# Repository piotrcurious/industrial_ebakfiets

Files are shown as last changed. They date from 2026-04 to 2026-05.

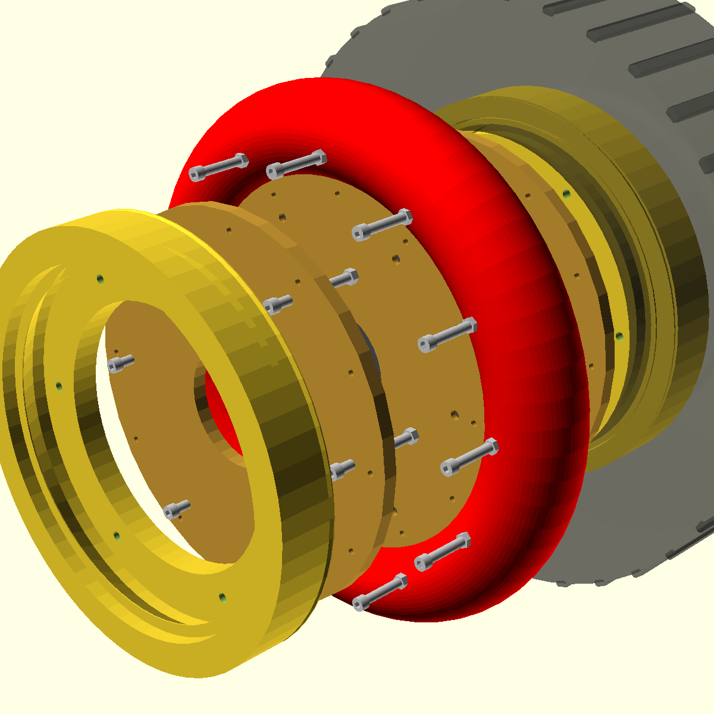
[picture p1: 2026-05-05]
docs/renders/front_wheel_exploded.png

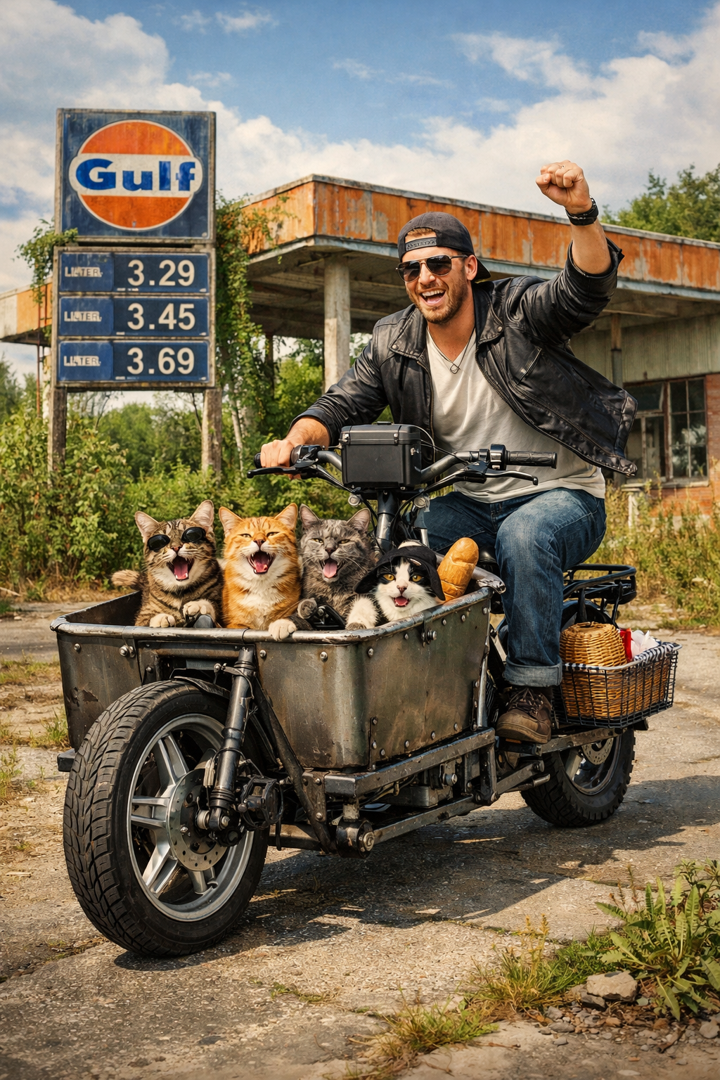
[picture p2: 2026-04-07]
file_000000008bf07243b2001178febfed57.png

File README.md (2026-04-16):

# Industrial E-Bakfiets

Welcome to the **industrial_ebakfiets** repository. This project aims to design and build heavy-duty cargo e-bikes using standard, widely available industrial and automotive parts.

## Project Concept

The **Industrial E-Bakfiets** takes a different approach:
- **Prioritize Durability and Serviceability**: Use heavy-duty parts that are easy to find and replace.
- **Electric-First Design**: Leverage powerful motors to offset the weight of a robust frame.
- **Automotive Components**: Incorporate standard car tires and split rims.

## 3D Mechanical Design (OpenSCAD)

The project features a full 3D mechanical model developed in **OpenSCAD**, ensuring dimensional accuracy and zero mechanical interference.

### Visual Renders (Orthographic & Perspective)
- **[Full Assembly Perspective](docs/renders/full_assembly_perspective.png)**
- **[Frame Side View](docs/renders/frame_side.png)**
- **[Front Fork Front View](docs/renders/front_fork_front.png)**
- **[Steering Head Section](docs/renders/steering_head_perspective.png)**
- **[Wheel & Hub Assembly](docs/renders/front_wheel_assy_perspective.png)**

### OpenSCAD Source Files
- **[Master Assembly](docs/models/full_assembly.scad)**
- **[Parts Library](docs/models/parts.scad)**
- **[Frame Model](docs/models/frame.scad)**
- **[Fork Model](docs/models/front_fork.scad)**

## Technical Documentation

Detailed descriptions of the core components and systems:

### Core Hardware Modules
- **[Mechanical Concept](docs/modules/mechanical_concept.md)**
- **[Mechanical Geometry](docs/modules/mechanical_geometry.md)**
- **[Frame Module](docs/modules/frame.md)**
- **[Front Wheel Module](docs/modules/front_wheel.md)**
- **[Steering Head Module](docs/modules/steering_head.md)**
- **[Brakes & Steering Module](docs/modules/brakes_steering.md)**
- **[Drivetrain Module](docs/modules/drivetrain.md)**
- **[Cargo Box Module](docs/modules/cargo_box.md)**

### Component Elements (Detailed Specs)
- **[Motor Adapter Plate](docs/elements/motor_adapter_plate.md)**
- **[High-Torque Arm](docs/elements/torque_arm.md)**
- **[Steering Bell Crank](docs/elements/steering_bell_crank.md)**
- **[Bearing Locking Collar](docs/elements/bearing_collar.md)**
- **[Steering Shaft](docs/elements/steering_shaft.md)**
- **[Front & Rear Dropouts](docs/elements/front_dropout.md)**
- **[Brake Mount Tabs](docs/elements/brake_mount_tab.md)**
- **[Bipod Kickstand](docs/elements/bipod_kickstand.md)**
- **[Stabilizer Units](docs/elements/stabilizer_unit.md)**
- **[Mudguard Stays](docs/elements/mudguard_stay.md)**

### Systems, Software & Maintenance
- **[Electrical Module](docs/modules/electrical.md)**
- **[Control & Software Module](docs/modules/control_software.md)**
- **[Ergonomics & Accessories](docs/modules/ergonomics_accessories.md)**
- **[Weather Protection](docs/modules/weather_protection.md)**
- **[Manufacturing Jigs](docs/modules/manufacturing_jigs.md)**
- **[Maintenance & Safety](docs/modules/maintenance_safety.md)**
- **[Regulatory Compliance](docs/modules/regulatory_compliance.md)**

## Assembly & Operations
- **[Assembly Guide](docs/assembly_guide.md)**
- **[Operator's Manual](docs/operator_manual.md)**
- **[Maintenance Log & Schedule](docs/modules/maintenance_log.md)**
- **[Testing & Validation Protocols](docs/modules/testing_validation.md)**
- **[Safety FMEA Analysis](docs/modules/safety_fmea.md)**
- **[System Telemetry Software](docs/modules/system_telemetry.md)**
- **[Electronics Wiring Pinout](docs/software/wiring_pinout.md)**

## Bill of Materials (BOM) Alternatives
1. **[Industrial Standard](docs/bom/industrial_standard.md)** (~$1,975)
2. **[Budget Salvage](docs/bom/budget_salvage.md)** (~$625)
3. **[Heavy Duty](docs/bom/heavy_duty.md)** (~$3,275)
4. **[Fastener Schedule & Torque Specs](docs/bom/fastener_schedule.md)**

---

*For historical reference, the original project description can be found in [README_ORIGINAL.md](README_ORIGINAL.md).*

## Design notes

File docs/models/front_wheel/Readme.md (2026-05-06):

wheel_assembly()          ← default render
wheel_exploded(gap=80)    ← rim halves pull apart on ±Z; tube visible in cavity
wheel_xray()              ← % modifier ghosts shells; internals solid in colour
wheel_section()           ← cube removes the +X/+Y quadrant

  hub_motor()
    _motor_shell()        ← rotor housing + flange rings + bearing recesses
    _motor_stator()       ← laminated core with 24 salient teeth
    _motor_magnets()      ← 28-pole tile ring inside shell
    _motor_bearings()     ← two annular rings
    axle()                ← flat-sided shaft + locknuts

  rim_half("outer"|"inner")
    _rim_ring()           ← rotate_extrude of 12-point profile
                             (hump → bead seat → well → split shoulder)
    _rim_split_ring()     ← annular bolt-flange boss at z = 0
    _rim_disc()           ← annular spider: hub clearance + 6 lightening holes
                             + 12 split-bolt holes

  split_bolts()           ← 12× M7 with hex head and hex nut
  valve_stem()            ← Schrader valve in outer half well
  inner_tube()            ← torus, CL at r ≈ 214 mm
  tire_body()             ← elliptical torus (radial × axial axes differ)

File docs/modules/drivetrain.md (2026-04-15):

# Drivetrain Module

The drivetrain of the industrial bakfiets is designed for secondary power and assistance, with a focus on simplicity and grease management.

## Pedal Power
### 1. Simple Derailleur System
- **Standard**: Shimano Altus or Deore 7-10 speed.

## Chain Management & Protection
To ensure operator safety and minimize maintenance in industrial environments, the chain is fully managed.

### 1. Chain Tubes
- **Material**: **12mm ID / 16mm OD Heavy-duty HDPE** (High-Density Polyethylene) tubing.
- **Function**: Encases the long return and drive runs of the chain, preventing grease contamination and reducing chain slap against the frame.

### 2. Mounting Clips
- **Design**: 3D-printable or steel-welded clips.
- **Fastening**: Secured to the 40x40mm main frame spars using **M5 Socket Head Screws**.
- **Alignment**: Tubes must be aligned to maintain a maximum 10-degree chain entry/exit angle into the sprockets.

## Transmission Components
### 1. Chain and Sprockets
- **Standard**: 1/2\" x 1/8\" heavy-duty bicycle or industrial-grade chain.

### 2. Bottom Bracket and Crankset
- **Crankset**: 170mm or 175mm length, 42T steel chainring.

## Rear Hub Motor
### 1. Motor Specification
- **Type**: 350W-500W Geared Hub Motor.
- **Dropout Spacing**: 135mm.
- **Mating**: Standard IS 6-bolt brake rotor mount.

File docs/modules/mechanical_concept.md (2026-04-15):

# Industrial E-Bakfiets: Mechanical Concept

This module describes the core mechanical architecture of the heavy-duty cargo bike, redesigned using a **Surface-to-Surface Connection** logic starting from the front automotive tire.

## 1. Assembly Chain
The design follows a logical physical connection path:
1.  **Front Tire (Anchor)**: 155/70 R13 automotive tire.
2.  **Front Hub Motor**: Mated to the tire rim center.
3.  **Front Fork**: Mated to the hub's M14 axle ends.
4.  **Steering Head**: Mated to the fork's 15mm steering shaft via 7202 bearings.
5.  **Main Frame**: Mated to the steering head's structural gusset.
6.  **Rear End**: Mated to the frame spars, including the 16" rear wheel and BB shell.

## 2. Key Dimensions
- **Wheelbase**: 1950 mm
- **Head Angle**: 68°
- **Trail**: ~73 mm (calculated from 45mm rake and 548mm tire OD)
- **Bed Width**: 810 mm (Standard Euro-pallet compatibility)
- **Ground Clearance**: 150 mm

## 3. Structural Elements
- **Frame Spars**: 40x40x2.5mm rectangular steel tubing.
- **Steering Head**: 1-1/4" Schedule 40 steel pipe (35.05mm ID).
- **Fork Blades**: 30x30x2.5mm rectangular steel tubing with 6mm laser-cut dropouts.

## 4. Design Philosophy
By starting the design from the "extreme" part (the front tire), we ensure that the most geometrically constrained component (the large automotive wheel) dictates the clearances for the fork and frame, rather than trying to "fit" the wheel into a pre-existing frame design.

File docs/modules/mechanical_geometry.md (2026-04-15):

# Mechanical Geometry Module

The handling and stability of the industrial bakfiets depend on precise frame and fork geometry, optimized for heavy cargo and low speeds.

## Frame Geometry
### 1. Head Angle and Steering Axis
- **Head Angle**: **68 degrees** from horizontal.
- **Steering Axis Offset (Rake)**: **45mm rake**.
- **Wheelbase**: **1950mm**.
- **Resulting Trail**: **~73mm** (calculated with 548mm OD front tire).

### 2. Drivetrain Geometry (Pedal Clearance)
To ensure the rider can pedal safely even when fully loaded:
- **Bottom Bracket Height**: **285mm** from the ground.
- **Pedal Clearance**: **115mm** with 170mm cranks at the 6 o'clock position (on level ground).
- **BB Offset**: The BB shell is mounted **85mm** above the centerline of the 40x40mm main frame rails.

## Steering Linkage Geometry
- **Steering Arms**: 10mm thick steel plates, **120mm length** from pivot center to rod end center.
- **Ratio**: **1:1 steering ratio** between handlebar and fork.
- **Kinematics**: With a +/- 45-degree limit, the linkage rod maintains an optimal angle to prevent over-centering or mechanical binding.

## Front Fork Design
- **Crown Width**: **250mm**.
- **Axle-to-Crown Length**: **360mm**.
- **Construction**: 40mm thick rectangular section crown with 30mm width blades.
- **Dropouts**: 8mm laser-cut plates for M14 axle.

## Rear Frame Geometry
- **Transition**: The main rails narrow via a header spar assembly to meet the steering head.
- **Rear Dropouts**: Spaced for **135mm** hub width (16" wheel).
- **Ground Clearance**: **150mm** (at the main frame rails).

## Mechanical Clearances
- **Tire to Fork**: 15mm per side.
- **Tire to Frame**: Minimum 20mm.
- **Chainline Clearance**: Optimized for 1x derailleur setup.

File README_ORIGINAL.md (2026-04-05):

# industrial_ebakfiets
e-bakfiets made out of standard industrial parts

Most bicycles are made with non-stsndard, vendor-lock-in enforcing parts.
This is often justified by fact bicycle must be made lightweight, condition seldom commerical bicycle really satisfies.

E-bikes, esp. cargo e-bikes break out this paradigm.
Cost of maintenance is much more important as bicycle weight is secondary.
Electric motor offsets the loss of weight.
Fact that bicycle carries cargo justifies use of more heavy duty parts including tires.

Main idea is to use car tire in the front,
13 inch 155/70 - very standard and cheap one, with load rating of 350kg.
To simplify the rim and free the user from dependency of tire shops to install the tire,
two parts rim can be used - similar to une used in wheelbarrows and Piaggio trikes
Rim disassembles into two parts , hiding tube inside.

Two electric motors are used

- 250W direct drive in the front
to provide efficiency during high speed and cruise.
Also for regen braking.

- 300W geared rear hub - to provide torque for uphill climb,
acceleration and starting up from a standstill.

Pedals could ideally provide only basic gears with wide gear ratio distribution.
Simplest chain etc. as most torque would be taken over by electric motors.
Reason to use derailleur instead of fixed gear is that chain tensioning is always needed anyway.
Also one gets about 500W peak from user, which is
important.

this GitHub repo is to house design plans of components, like hubs, rims ESC and software.

Below is example BOM made by BingAI:
To modify the BOM so that the bakfiets is electric, you would need to add some parts and modify some existing ones. Here is an example of a possible modified BOM:

| Part | Quantity | Source | Cost |
| --- | --- | --- | --- |
| Frame | 1 | Salvaged from an old bike or welded from steel pipes | $50 |
| Front wheel hub | 1 | 250W direct drive hub motor¹²³ with built-in controller and sensor. This replaces the Piaggio rim and provides power to the front wheel. | $100 |
| Front wheel spokes | 36 | Salvaged from an old bike or bought online | $10 |
| Front wheel rim | 1 | 13 inch 155/70 profile car tire | $25 |
| Front wheel tube | 1 | Bought online or from a local shop | $5 |
| Rear wheel hub | 2 | Geared hub motor with built-in controller and sensor. This replaces the rear wheel hubs and provides power to the rear wheels. You can choose different power ratings depending on your needs, such as 250W, 350W, 500W, etc. Geared hub motors are lighter and more efficient than direct drive hub motors, but they also have more moving parts and may wear out faster. | $200-$400 |
| Rear wheel spokes | 72 | Salvaged from an old bike or bought online | $20 |
| Rear wheel rim | 2 | Salvaged from an old bike or bought online | $40 |
| Rear wheel tube | 2 | Bought online or from a local shop | $10 |
| Bearings | 4 | Cheap industrial bearings or salvaged from an old bike or car parts. These are only needed for the front fork and the steering head. The hub motors have their own bearings. | $20 |
| Chain | 1 | Salvaged from an old bike or bought online. This is optional, as you can use the hub motors to propel the bakfiets without pedaling. However, having a chain can help you save battery power and exercise your legs. You can also use a belt drive instead of a chain for less noise and maintenance.  | $10-$30 |
| Chainring | 1 | Salvaged from an old bike or bought online. This is optional, as you can use the hub motors to propel the bakfiets without pedaling. However, having a chainring can help you save battery power and exercise your legs. You can also use a belt drive instead of a chain for less noise and maintenance.  | $10-$30 |
| Crankset | 1 | Salvaged from an old bike or bought online. This is optional, as you can use the hub motors to propel the bakfiets without pedaling. However, having a crankset can help you save battery power and exercise your legs. You can also use a belt drive instead of a chain for less noise and maintenance.  | $15-$45 |
| Pedals | 2 | Salvaged from an old bike or bought online. These are optional, as you can use the hub motors to propel the bakfiets without pedaling. However, having pedals can help you save battery power and exercise your legs. You can also use clipless pedals for more efficiency and comfort.  | $10-$40 |
| Brake levers | 2 | Salvaged from an old bike or bought online. These should have electric switches that can cut off the power to the hub motors when braking. This can improve safety and regenerative braking efficiency. | $10-$20 |
| Brake cables and housing | 2 | Salvaged from an old bike or bought online. These should be compatible with the brake levers and calipers. | $10-$20 |
| Brake calipers and pads | 2 (front and rear) or 3 (front and two rear) depending on the design of the frame and wheels. Salvaged from an old bike or car parts or bought online. Alternatively, use drum brakes or disc brakes if available. Drum brakes are more durable and require less maintenance, but are heavier and more expensive. Disc brakes are more powerful and responsive, but are also heavier and more expensive. They also require special hubs and mounts.  | $30-$60 |
| Handlebar and stem | 1 each. Salvaged from an old bike or bought online. Choose a comfortable and ergonomic design that suits your riding style and posture.  | $20-$40 |
| Grips or tape for handlebar. Choose a comfortable and durable material that suits your preference.  | $5-$10 |
| Seatpost and clamp. Salvaged from an old bike or bought online. Choose a suitable length and diameter that fits your frame and seat.  | $10-$20 |
| Seat or saddle. Choose a comfortable and ergonomic design that suits your anatomy and riding style.  | $15-$30 |
| Headset. Salvaged from an old bike or bought online. Choose a suitable type and size that fits your frame and fork.  | $10-$20 |
| Fork. Salvaged from an old bike or welded from steel pipes. Choose a suitable length and rake that matches your frame geometry and wheel size.  | $20-$40 |
| Box for cargo. Made from wood, metal, plastic or other materials. Choose a suitable size, shape and weight that fits your frame and meets your needs. You can also add features such as seats, belts, cushions, covers, locks, lights, etc. for safety and comfort of your passengers or goods.  | $50-$100 |
| Battery pack | 1 | Bought online or from a local shop. Choose a suitable voltage, capacity, chemistry, size, shape and weight that matches your hub motors and fits your frame or box. You can also build your own battery pack from individual cells, but this requires more skills, tools and safety precautions. The higher the voltage, the faster the speed; the higher the capacity, the longer the range; the higher the chemistry (such as lithium-ion), the lighter the weight; but also the higher the cost. A common battery pack for e-bikes is 36V 10Ah lithium-ion, which can provide about 360Wh of energy and power a 250W hub motor for about an hour at full throttle (depending on terrain, wind, rider weight, etc.). You can also use multiple battery packs in parallel or series to increase the capacity or voltage respectively. | $100-$300 |
| Battery charger | 1 | Bought online or from a local shop. Choose a suitable type, voltage, current and plug that matches your battery pack and your local power grid. A common charger for e-bikes is 36V 2A, which can charge a 36V 10Ah battery pack in about 5 hours (depending on the state of charge). You can also use a faster charger with higher current, but this may reduce the battery life span. You should also use a smart charger with automatic cutoff and balancing features to prevent overcharging or undercharging of individual cells in the battery pack. | $20-$50 |
| Battery management system (BMS) | 1 | Bought online or from a local shop. This is a circuit board that monitors and controls the battery pack's voltage, current, temperature, state of charge, etc. It protects the battery pack from overcharging, overdischarging, short circuiting, overheating, etc. It also balances the individual cells in the battery pack to ensure optimal performance and longevity. A BMS is usually included in the battery pack or the charger, but you can also buy a separate one if needed. Choose a suitable type and size that matches your battery pack's specifications and wiring. | $10-$50 |
| Throttle | 1 | Bought online or from a local shop. This is a device that allows you to control the speed of the hub motors by varying the voltage or current sent to them. There are different types of throttles, such as twist grip, thumb lever, trigger, etc. Choose a suitable type and size that fits your handlebar and preference. You can also use a pedal assist sensor (PAS) instead of or in addition to a throttle, which detects your pedaling speed and provides proportional assistance from the hub motors. This can make the riding experience more natural and save battery power. | $10-$20 |
| Display | 1 | Bought online or from a local shop. This is a device that shows you various information about your e-bike, such as speed, distance, battery level, power mode, etc. There are different types of displays, such as LCD, LED, etc. Choose a suitable type and size that fits your handlebar and preference. You can also use a smartphone app instead of or in addition to a display, which can connect to your hub motors or battery pack via Bluetooth or other wireless protocols and provide more features and functions. | $20-$50 |
| Wiring harness | 1 | Bought online or from a local shop. This is a set of wires and connectors that link all the electrical components of your e-bike together. It should be compatible with your hub motors, battery pack, BMS, throttle, display, etc. It should also be long enough to reach all the parts and short enough to avoid excess slack. It should also be waterproof, durable and well insulated to prevent electric shocks or fire hazards. You can also make your own wiring harness from individual wires and connectors if you have the skills and tools. | $10-$30 |

The total cost of this modified BOM is estimated to be between $700 and $1200, depending on the availability and quality of the parts. This is still cheaper than buying a new electric bakfiets, which can cost over $3000. However, this modified BOM is only a rough guide and you may need to adjust it according to your specific situation and preferences. You may also need some tools and skills to assemble the parts together, such as wrenches, screwdrivers, pliers, hammers, drills

Source: Conversation with Bing, 4/18/2023
(1) Best e-bike motors: Everything you need to know | Cyclingnews. https://www.cyclingnews.com/features/best-e-bike-motors/.
(2) 250 watt hub motor. Is it Enough? | ELECTRICBIKE.COM. https://www.electricbike.com/250-watt-hub-motor/.
(3) 250W Gear Hub Motor, 24V/ 36V/ 48V, 35 N.m | ATO.com. https://www.ato.com/250w-gear-hub-motor.

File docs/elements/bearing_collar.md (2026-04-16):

# Element: Bearing Locking Collar

The locking collars prevent vertical movement of the 15mm steering shaft within the angular contact bearings.

## Technical Specifications
- **Material**: 4140 Steel or 304 Stainless Steel.
- **Outer Diameter (OD)**: 35.0mm (Matches bearing race OD).
- **Inner Diameter (ID)**: 15.1mm.
- **Thickness**: 15.0mm.

## Geometry
- **Locking Pattern**: 6x M5 threaded radial holes spaced at 60 degrees.

## Fastener Requirements
- **Set Screws**: 6x M5x8mm Grade 12.9 Cup Point Set Screws.

## Installation Notes
- Position the collar directly against the inner race of the 7202 bearing.
- Tighten the 6 set screws in a star pattern to ensure even pressure on the 15mm shaft.
- A small flat ground onto the 15mm shaft at the set-screw locations is recommended for heavy-duty applications.

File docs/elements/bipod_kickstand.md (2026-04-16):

# Element: Bipod Kickstand

A heavy-duty, wide-base kickstand is essential for loading 350kg of cargo without the vehicle tipping.

## Technical Specifications
- **Material**: 25mm x 3.0mm Circular Steel Tubing.
- **Pivot Pin**: 12mm Hardened Steel with integrated grease fitting (Zerk).
- **Base Width**: 400mm (Deployed).
- **Leg Length**: 350mm.

## Manufacturing Notes
- The two legs should be bent at 8 degrees outward to provide a stable footprint.
- Large 60mm diameter "feet" plates should be welded to the bottom of the legs to prevent sinking into soft ground.
- The return mechanism uses dual 2.5mm wire tension springs.

## Installation Notes
- Weld the 10mm steel pivot plate to the center of the cargo bed main spars.
- Ensure the stand clears the chain and the 16-inch rear wheel when retracted.
- Adjust the return spring tension so the stand snaps firmly against the frame during transit.

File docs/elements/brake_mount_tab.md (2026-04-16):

# Element: Brake Mount Tab (ISO)

Standardized mounting tabs for hydraulic disc brake calipers.

## Technical Specifications
- **Material**: 6.0mm or 8.0mm Mild Steel.
- **Standards**: ISO 51mm (distance between mounting holes).

## Geometry
- **Mounting Holes**: 2x 6.5mm (Clearance for M6).
- **Hole Spacing**: 51.0mm center-to-center.

## Installation Notes
- Weld to the dropout plate or fork blade.
- **Positioning**: Use a centering jig with the disc rotor installed to ensure the caliper sits exactly over the brake track.
- The tab must be perpendicular to the axle axis.

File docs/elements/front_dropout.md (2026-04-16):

# Element: Front Fork Dropout Plate

The front dropouts are the high-stress interface between the fork legs and the M14 motor axle.

## Technical Specifications
- **Material**: 8.0mm Structural Mild Steel.
- **Manufacturing**: Laser-cut.

## Geometry
- **Axle Slot**: 14.2mm (Width) x 25.0mm (Depth). Designed for M14 axle with 10mm flats.
- **Mudguard Mounting**: 1x 6.5mm hole for M6 stay attachment.
- **Brake Mount**: Integrated ISO tabs for 203mm rotor clearance.

## Installation Notes
- Weld to the center of the 30mm wide fork blades.
- Ensure the two dropout slots are perfectly aligned using a 190mm dummy axle during welding.
- Chamfer the entry of the slot for easier wheel installation.

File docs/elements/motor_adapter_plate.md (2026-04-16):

# Element: Motor-to-Rim Adapter Plate

The Adapter Plate is the critical interface that bridges the high-torque Golden Motor Magic Pie 5 spoke flange to a standard 13-inch automotive split rim.

## Technical Specifications
- **Material**: 12.0mm Mild Steel (Grade 43) or 10.0mm Stainless Steel (304).
- **Outer Diameter (OD)**: 330mm.
- **Inner Bore (ID)**: 100mm (clearance for motor hub).
- **Manufacturing**: Laser-cut or CNC Waterjet.

## Hole Patterns
1. **Inner Pattern (Motor Interface)**:
   - **PCD**: 320mm (based on Golden Motor spoke flange).
   - **Holes**: 12x 5.5mm (Clearance for M5).
   - **Spacing**: 30 degrees.
2. **Outer Pattern (Rim Interface)**:
   - **PCD**: 260mm.
   - **Holes**: 6x 8.5mm (Clearance for M8).
   - **Spacing**: 60 degrees.

## Fastener Requirements
- **Inner**: 12x M5x20mm Grade 12.9 Socket Head Cap Screws (per plate).
- **Outer**: 6x M8x140mm Grade 10.9 Bolts (shared with rim sandwich).

## Installation Notes
- Apply medium-strength thread locker to all M5 bolts.
- Ensure the motor flange is clean and free of paint where the adapter plate meets to ensure a true mechanical fit.

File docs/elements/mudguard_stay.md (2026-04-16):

# Element: Front Mudguard Stay

The stays provide a rigid 3-point mounting system for the oversized 170mm wide front mudguard.

## Technical Specifications
- **Material**: 8mm Round Steel Rod or 10x3mm Flat Bar.
- **Length**: Approx 280mm (Custom fit required based on tire clearance).

## Geometry
- **Eyelet (Dropout side)**: 6.5mm hole for M6 mounting.
- **Eyelet (Mudguard side)**: 5.5mm hole for M5 mounting.

## Fastener Requirements
- **Lower**: 1x M6x16mm Bolt (per stay).
- **Upper**: 1x M5x12mm Bolt (per stay).

## Installation Notes
- Ensure a minimum clearance of 20mm between the tire tread and the mudguard blade.
- The stays should be bent to avoid interference with the 203mm brake rotor and the hub motor housing.

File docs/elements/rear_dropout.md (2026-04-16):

# Element: Rear Frame Dropout Plate

The rear dropouts accommodate the 135mm hub motor and the 7-10 speed derailleur hanger.

## Technical Specifications
- **Material**: 8.0mm Structural Mild Steel.
- **Manufacturing**: Laser-cut.

## Geometry
- **Axle Slot**: 10.2mm (standard rear hub axle).
- **Derailleur Hanger**: Integrated tab with M10x1.0 threaded hole, offset 10mm outward.
- **Brake Mount**: IS (International Standard) tabs.

## Installation Notes
- Weld to the ends of the tapered rear triangle tubes.
- Use a 135mm precision spacer during welding to prevent the "pulling" of the dropouts as the welds cool.

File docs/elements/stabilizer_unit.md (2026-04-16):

# Element: Stabilizer Unit (Landing Feet)

The stabilizer units provide additional lateral support during heavy loading/unloading operations, preventing the frame from twisting or tipping when the cargo is off-center.

## Technical Specifications
- **Material**: 35mm x 35mm x 2.5mm Square Steel Tubing (Outer), 25mm x 25mm x 2.5mm (Inner).
- **Drive Mechanism**: M16x250mm Threaded Rod (Grade 8.8).
- **Deployment Range**: 0 - 200mm.

## Manufacturing Notes
- Weld an M16 nut to the top of the inner 25mm tube.
- The outer 35mm tube is welded vertically to the four corners of the cargo bed main spars.
- A 100mm diameter "Elephant Foot" plate should be welded to the bottom of the inner tube to distribute load on soft surfaces.

## Installation Notes
- Ensure the stabilizers are fully retracted before transit to maintain ground clearance.
- Use a standard 24mm wrench or a dedicated handle to deploy the M16 screw.
- Lubricate the threaded rod with heavy marine grease.

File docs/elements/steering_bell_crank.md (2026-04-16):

# Element: Steering Bell Crank

The bell cranks convert the linear motion of the steering tie-rod into rotational motion for the fork and handlebars.

## Technical Specifications
- **Material**: 10.0mm Mild Steel.
- **Effective Length**: 120mm (Pivot center to rod-end center).
- **Manufacturing**: Laser-cut.

## Geometry
- **Main Bore**: 15.1mm (Press-fit or sliding fit on 15mm steering shaft).
- **Rod-End Hole**: 10.2mm (Clearance for M10 rod end).
- **Locking Hole**: 5.0mm radial hole for an M5 set-screw or roll pin to lock the crank to the shaft.

## Fastener Requirements
- **Linkage**: M10x1.5 LH/RH Rod Ends.
- **Lock**: M5x15mm Grade 12.9 Set Screw.

## Installation Notes
- The fork-mounted bell crank and the handlebar-mounted bell crank must be perfectly parallel when the front wheel is pointed straight.
- Use a high-strength thread locker on the M5 locking set-screw.

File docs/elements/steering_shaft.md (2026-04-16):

# Element: Steering Shaft (Pivot Axis)

The steering shaft is the primary pivot for the front end, transferring torque from the handlebars to the linkage.

## Technical Specifications
- **Material**: 15.0mm Precision Ground Steel Rod (h8 tolerance or better).
- **Length**: 500mm (Standard) - trim to fit.
- **Surface**: Hardened or Chrome-plated to prevent corrosion and wear in the bearing seats.

## Installation Notes
- Ensure the shaft is free of burrs before sliding through the 7202 bearings.
- The shaft is held in place by two Bearing Locking Collars (Top and Bottom).
- Two flats should be machined/ground at the locations of the Bell Crank set-screws to ensure a non-slip mechanical connection.
- Lubricate with heavy-duty lithium grease before final assembly.

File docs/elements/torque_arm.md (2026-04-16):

# Element: Heavy-Duty Torque Arm

The torque arm prevents the high-torque motor axle (14mm with 10mm flats) from rotating inside the fork dropouts, which would damage the fork and the motor wiring.

## Technical Specifications
- **Material**: 10.0mm Structural Mild Steel (S275 or higher).
- **Length**: 140mm (Center of axle to center of frame anchor).
- **Manufacturing**: Laser-cut.

## Geometry
- **Axle Slot**: 14.2mm circle with 10.2mm parallel flats.
- **Anchor Hole**: 8.5mm (Clearance for M8 bolt).

## Fastener Requirements
- **Anchor**: 1x M8x30mm Grade 10.9 Bolt.
- **Nut**: 1x M8 Nyloc Nut.
- **Washer**: 2x M8 Heavy Duty (Large OD) Washers.

## Installation Notes
- The torque arm must be mounted on the side where the motor cable exits the axle.
- Ensure the anchor bolt is secured to a dedicated 8mm steel tab welded to the fork leg.
- There should be zero play between the motor flats and the torque arm slot.

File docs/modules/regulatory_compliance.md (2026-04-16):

# Regulatory Compliance and Safety Standards

The Industrial E-Bakfiets is designed as a heavy-duty Electrically Power Assisted Cycle (EPAC). Depending on the jurisdiction, different regulations apply.

## 1. European Union (EN 15194)
To comply with the standard EPAC regulations in the EU:
- **Continuous Power**: The sum of both motors should be electronically limited to **250W continuous**.
- **Cut-off Speed**: Assistance must cut off at **25km/h**.
- **Activation**: Assistance must only be provided when the rider is pedaling (PAS sensor mandatory). Throttles are permitted only for "walk-assist" up to 6km/h.

*Note: In many jurisdictions, heavy cargo bikes can be registered as 'L-category' vehicles if they exceed these limits, requiring insurance and a license.*

## 2. North America (Class 1, 2, and 3)
The dual-motor system can be configured to meet US e-bike classes:
- **Class 1**: Pedal-assist only, 20mph limit.
- **Class 2**: Throttle-assist permitted, 20mph limit.
- **Class 3**: Pedal-assist only, 28mph limit.
- **Power Limit**: Typically 750W (1.0 hp).

## 3. Structural Safety Standards
The design incorporates safety factors derived from industrial equipment standards:
- **Fastener Safety**: Critical joints (axles, steering, brakes) use Grade 10.9 or 12.9 fasteners to provide a 4x safety factor against shear failure under maximum load (350kg).
- **Braking Performance**: The 203mm front rotor is sized to dissipate the heat generated by stopping a 450kg total system weight (vehicle + rider + cargo) from 25km/h on a 10% grade.
- **Redundancy**: The dual-motor system provides "limp-home" capability; if one motor or controller fails, the second can provide enough torque to move the vehicle to a safe service location.

## 4. Electrical Safety
- **Fuse Protection**: Each battery circuit must include a high-current DC fuse (e.g., 40A MIDI fuse).
- **IP Rating**: All enclosures and connectors are specified as **IP65** or higher to protect against water ingress during rain or industrial cleaning.

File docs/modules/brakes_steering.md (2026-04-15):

# Brakes and Steering Module

The brakes and steering of the industrial bakfiets are designed to handle high loads and provide safe, predictable control.

## Steering System
### 1. Steering Geometry
- **Design**: Low-slung steering linkage with heavy-duty rod ends.
- **Steering Linkage Rod**: **15mm OD x 2.0mm WT** steel tubing.
- **Rod Ends**: Standard industrial M10 or M12 rod ends.
- **Thread Engagement**: Minimum **20mm** engagement on all rod end threads to prevent pull-out under load.

### 2. Steering Stops
To prevent the steering linkage from binding or the front wheel from hitting the cargo box, physical stops are integrated:
- **Design**: 10mm solid steel pins welded to the fork crown.
- **Interface**: Matching 6mm reinforced steel strike plates welded to the head tube housing.
- **Travel Limit**: Exactly **+/- 45 degrees** from center.

### 3. Dimensions, Clearances & Fits
- **Steering Column OD**: 15.0mm precision steel rod.
- **Bearing**: Pair of 7202 Angular Contact Bearings.

## Braking System
The industrial bakfiets uses a triple-redundant braking system.

### 1. Front Braking (Main Stopping Power)
- **Disc Rotor**: 203mm diameter, 2.0mm thick (6-bolt pattern).
- **Caliper**: Hydraulic 4-piston caliper (PM mount).

### 2. Rear Braking (Control and Parking)
- **Disc Rotor**: 203mm diameter.
- **Caliper**: Hydraulic/Mechanical (IS mount).
- **Parking Brake**: A **locking brake lever** is required on the rear brake.

## Component Sourcing
In budget builds, salvaged **Calipers/Rotors** from mountain bikes or small mopeds can be used, provided they match the 203mm/180mm sizing and mounting standards (PM/IS).

## Tolerances and Fit
- **Steering Alignment**: Within +/- 1 degree.
- **Stop-Pin Tolerance**: +/- 0.5mm to ensure symmetrical turning radius.

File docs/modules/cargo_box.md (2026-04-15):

# Cargo Box Module

The cargo box of the industrial bakfiets is designed for maximum utility, standard freight compatibility, and extreme durability.

## Construction Materials
### 1. Main Panels
- **Specification**: **12mm Marine-grade Plywood**.

### 2. Reinforcements
- **Edge Protection**: **25mm x 25mm x 3mm Steel Angle**.

## Modular Divider System
To prevent cargo movement during transit, the box is equipped with an adjustable partitioning system.

### 1. Logistics Rails
- **Standard**: **50mm E-track Rails** (Zinc-plated steel).
- **Mounting**: Bolted to the internal horizontal mid-line of the box using M6 countersunk bolts.

### 2. Partition Panels
- **Material**: 9mm Phenolic plywood.
- **Hardware**: Integrated **E-track Spring Fittings** allow the panels to be clicked into place at any point along the rails.

## Dimensions and Compatibility
- **Internal Width**: 810mm.
- **Internal Length**: 1350mm.
- **Standard Load**: Fits one **Standard Euro-pallet** (with extra room for gear).

## Mounting and Security
- **Frame Interface**: Secured via **8x M10 Grade 8.8 Bolts**.
- **Tie-Down Points**: Four integrated **D-ring anchor points**.

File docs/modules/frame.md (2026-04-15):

# Frame Module

The frame of the industrial bakfiets is designed to be sturdy, repairable, and built from standard materials available at any steel supplier.

## Material Selection
### 1. Steel Rectangular Tubes (Main Spars & Gooseneck)
- **Dimensions**: 40x40mm with 2.5mm wall thickness.
- **Gooseneck Riser**: 500mm vertical offset with 450mm horizontal reach to bridge high steering head to low bed. Reinforced with 10mm diagonal gussets.

### 2. Head Tube (Redesigned 7202 Setup)
- **Standard**: **1-1/4\" Schedule 40 Steel Pipe** (Nominal ID: 35.05mm).

## Design Philosophy
### 1. Longitudinal Stiffness
The main cargo bed is supported by two parallel rails. Total bed width is **834mm** (810mm internal + 12mm walls), and length is **1374mm** (1350mm internal).

### 2. Low Center of Gravity (16-inch Rear Wheel)
The use of a **16-inch rear wheel** lowers the center of gravity and allows for a more compact rear frame design.

### 3. Bottom Bracket and Hanger Integration
- **Bottom Bracket**: A standard BSA 68mm shell is welded to a **10mm steel bridge plate** positioned 85mm above the main rail centerline.
- **Rear Triangle**: The main rails taper from 810mm width to **135mm width** at the rear dropouts using angled 40x40mm tube sections.
- **Derailleur Hanger**: Integrated 8mm laser-cut hanger on the drive-side dropout.

### 4. Screw-Driven Cargo Bed Stabilizer System
- **Design**: Telescopic square steel tubing with M16/M20 threaded rod.

## Mechanical Integration & Assembly
### 1. Dropout Integration
- **Dropout Plate**: 6mm-8mm laser-cut steel plates.

### 2. Headset Integration (No-Machining Design)
- **Locking Method**: Six 5mm radial holes for internal bearing stopping collars.
- **Reinforcement**: Triangular gussets (60x60x10mm) at top and bottom of the head tube to frame header plate junction.
- **Steering Linkage**: 15mm steel rod connecting the fork lower pivot to the handlebar column.
- **Cable Management**: Integrated eyelets every 300mm along the left spar.

## Tolerances and Fit
- **BB Squareness**: Within +/- 0.2mm.
- **Rear Dropout Alignment**: Within +/- 1.0mm over the wheelbase length.
- **Ground Clearance**: 150mm.

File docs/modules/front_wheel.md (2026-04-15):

# Front Wheel Module

The front wheel of the industrial bakfiets is designed for heavy-duty cargo transport, utilizing standard automotive parts for durability and ease of maintenance.

## Components
### 1. 13-inch Car Tire (155/70 R13)
- **Dimensions**: 155mm Width, 548mm Diameter.
- **Load Rating**: 350kg.

### 2. Two-Part "Split" Rim
- **Design**: Two halves bolted together (industrial type).
- **Bolt Pattern**: 6x260mm PCD.
- **Fasteners**: **6x M8x140mm Grade 10.9 Bolts** with heavy-duty washers and **M8 Nyloc nuts**. (Tighten to 25-30Nm). These bolts sandwich both rim halves and both motor flanges for maximum rigidity.

### 5. Front Mudguard Assembly
- **Main Blade**: High-impact ABS or Aluminum (170mm width).
- **Crown Mounting**: Heavy-duty offset bracket secured to the fork crown with **2x M6x20mm Grade 10.9 Bolts**.
- **Stay Mounting**: Dual 8mm steel stays connecting the mudguard sides to the fork dropouts via **2x M5x12mm Bolts**.

### 3. Inner Tube
- **Specification**: 13-inch automotive tube with Schrader valve.

### 4. Front Hub Motor: Golden Motor Magic Pie 5 (Fatbike Edition)
- **Type**: Direct Drive BLDC with internal Sine-wave controller.
- **Diameter**: 320mm (Spoke flange), 310mm (Housing).
- **Axle**: 14mm with 10mm flats, **190mm Dropout Spacing** (Fatbike standard).
- **Axle Fasteners**: **2x M14x1.5 Flange Nuts** with **2x M14 High-Torque Washers** (tabbed).
- **Braking**: 203mm Disc Rotor with 6-bolt ISO mount (44mm PCD).
- **Torque Arm**: 10mm laser-cut steel plate (10.2mm cutout) secured to the fork leg using **1x M8x30mm Grade 10.9 Bolt and Nut**.

### 5. Motor-to-Rim Adapters
- **Design**: 2x 12mm Brass or Steel adapter plates.
- **Interface**: Bridges the 56-hole motor spoke flange to the 6-bolt rim pattern.
- **Fasteners (Inner)**: 12x M5x20mm Grade 12.9 bolts per side.
- **Fasteners (Outer)**: 6x M8x140mm bolts (shared with rim assembly).

## Mechanical Integration & Assembly
### 1. Front Power Housing (Fork Mounted)
- **Housing Mounting**: Oversized BLDC box secured to fork tabs using **4x M6x16mm Stainless Steel Hex Bolts** and rubber vibration dampers.

## Assembly & Disassembly Methods
### Assembly
1. Deflate tube and sandwich tire/tube between rim halves.
2. Align the assembly with the Hub Motor flanges (Sandwich: Flange-Rim-Rim-Flange).
3. Pass 6x M8x140mm bolts through the pattern. Tighten to **30Nm**.
3. Slide axle into dropouts.
4. Install torque arm on the axle and bolt to fork leg.
5. Tighten M14 axle nuts to **50Nm**.

### Disassembly
1. Fully deflate tire.
2. Unbolt M14 axle nuts and M6 torque arm bolt.
3. Remove wheel and unbolt M8 rim bolts.

## Tolerances
- **Axle-to-Dropout**: 0.2mm clearance (10.2mm slot for 10.0mm flats).
- **Fastener Grade**: Grade 10.9 required for rim and axle-related hardware.

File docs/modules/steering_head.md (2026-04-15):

# Industrial E-Bakfiets: Steering Head Module

The steering head is the primary pivot point of the bicycle, connecting the fork to the main frame. It is designed for high-load industrial use using a "no-machining" approach.

## 1. Physical Interface
The assembly is centered on the steering axis, tilted at **68 degrees** from the horizontal.

- **Lower Interface**: Mates with the fork crown via a 15mm precision shaft.
- **Internal Interface**: Houses two **7202 angular contact bearings** (15x35x11mm).
- **Outer Interface**: 1-1/4" Schedule 40 steel pipe (OD 42.16mm, ID 35.05mm).
- **Structural Interface**: A 20mm thick steel gusset plate welded to the HT, providing the mating surface for the main frame connection member.

## 2. Bearing Arrangement
Angular contact bearings are used to handle both the radial loads from steering and the significant axial (thrust) loads from the cargo weight.
- **Top Bearing**: Oriented to take upward thrust.
- **Bottom Bearing**: Oriented to take downward thrust.
- **Preload**: Achieved using M15 shaft collars and shim washers.

## 3. Surface-to-Surface Mating logic
In the digital model, the steering head is located by moving from the **Fork Crown** up the **Steering Shaft**. The Frame is then located by moving from the **HT Gusset Face** backwards. This ensures that any change in fork length or HT diameter automatically propagates through the rest of the chassis geometry without manual recalculation.

## 4. Safety Specs
- **Travel Limit**: +/- 45 degrees via 10mm steel stop pins.
- **Fasteners**: M8 Grade 12.9 for the gusset-to-frame connection (if bolted) or full-penetration welds.

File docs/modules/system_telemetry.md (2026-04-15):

# System Telemetry and Supervisory Control

To ensure the reliability of the industrial dual-motor system, a "Supervisory Controller" is recommended. While the hub motors operate on their own internal/external BLDC controllers, the Supervisor acts as a cockpit dashboard and safety watchdog.

## 1. Hardware Overview
- **Microcontroller**: Arduino Nano, ESP32, or Teensy 4.0.
- **Display**: High-contrast 20x4 Character LCD or Sunlight-readable OLED.
- **Sensors**:
  - **Voltage Divider**: To monitor the 48V-60V main traction battery.
  - **Hall-Effect Current Sensors**: (e.g., ACS712 or ACS758) on the positive lead of each motor controller.
  - **Thermistor (NTC 10k)**: Embedded in the motor windings or attached to the motor housing to monitor heat soak during heavy climbing.

## 2. Telemetry Metrics
The system should track and display the following in real-time:
- **Voltage (V)**: Critical for determining State of Charge (SOC) and identifying voltage sag under load.
- **Amperage (A)**: Individual current for Front and Rear motors. This helps detect if one motor is working significantly harder (e.g., due to a mechanical issue or mismatched speed limits).
- **Power (W)**: Total instantaneous power consumption ($V \times (A_{front} + A_{rear})$).
- **Temperature (C)**: Thermal monitoring for both motors to prevent stator demagnetization.

## 3. Safety Logic
### Thermal Throttling
If either motor exceeds **85°C**, the Supervisor should trigger an audible alarm. Advanced implementations can use a relay or signal intercept to pull the throttle signal low, forcing the operator to slow down until the system cools.

### Low Voltage Cutoff (LVC)
While BLDC controllers have built-in LVC, the Supervisor provides a secondary visual warning when the battery reaches **42.0V** (for a 48V pack), allowing the operator to return to base before the BMS shuts down the system.

## 4. Wiring Diagram Integration
The Supervisor is powered by the **12V DC-DC converter** bus. Signal wires for the current sensors and thermistors should be shielded to prevent interference from the high-current phase wires of the motors.

- **[Reference Implementation (Arduino Code)](../software/system_monitor.ino)**

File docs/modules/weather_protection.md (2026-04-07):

# Weather Protection Module

The industrial bakfiets can be equipped with a modular canopy system to protect cargo and electrical units from environmental conditions.

## Canopy Structure
### 1. Frame
- **Material**: 15mm OD x 1.5mm WT Steel Tubing.
- **Design**: Hooped frame with longitudinal stringers for rigidity.
- **Mounting**: Four corner **M8 Bolt-on Sockets** welded to the exterior of the cargo box skeleton.

### 2. Cover Materials
- **Front Windshield**: **2mm Clear Polycarbonate** sheet, UV-stabilized, bolted to the front hoop.
- **Side/Rear Curtains**: **650gsm Heavy-duty Industrial PVC** (truck tarp quality).
- **Features**: Roll-up side panels with industrial Velcro or heavy-duty snap fasteners.

## Mechanical Integration
- **Socket Interface**: The 15mm frame tubes slide into the M8-locked sockets for easy removal when not required (Modular Design).
- **Drainage**: The canopy is pitched 5 degrees rearward to ensure water runoff away from the operator.

## Assembly Methods
1. Weld the four socket units to the cargo box steel angle edges.
2. Bend 15mm tubing to form hoops.
3. Attach polycarbonate and PVC using industrial adhesives and stainless fasteners.
4. Insert hoops into sockets and lock with M8 bolts.

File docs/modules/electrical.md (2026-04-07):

# Electrical Module

The industrial bakfiets uses a decentralized, dual-battery, dual-motor electrical system for maximum efficiency, redundancy, and reduced wiring losses.

## Decentralized Architecture
Instead of a single central battery and controller, the system is split into two localized power units.

### 1. Front Power Unit (Fork Mounted)
- **Location**: Mounted on the custom front fork.
- **Front Battery Retention**: Secured using **2x 20mm rubber-lined stainless steel straps** with M6 T-bolt tensioners.
- **Padding**: 4mm EVA high-density foam at all contact points.

### 2. Rear Power Unit (Frame Mounted)
- **Location**: Mounted on the main frame.
- **Rear Battery Retention**: Secured with identical stainless steel straps and foam padding.

## Dual-Battery Equalizer System
- **Specification**: **8AWG or 10AWG silicone-insulated wire**.

## Cable Management & Routing (Electrical)
To ensure the longest possible life for the electrical system, cables are protected from environmental and mechanical damage.

### 1. Routing Paths
- **High-Current**: Lengths under **500mm**.
- **Impact Protection**: Routed through **welded steel "Cable Bridges"**.

## Tolerances and Safety
- **Retention Force**: Battery mounting straps must withstand **3G vertical acceleration** without shifting.
- **Bend Radius**: Minimum bend radius for power cables is **10x the cable diameter**.

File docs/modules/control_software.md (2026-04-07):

# Control and Software Module

The industrial bakfiets uses a decentralized control system to manage its dual hub motors, ensuring synchronized performance and operator safety.

## Control Architecture
The system relies on parallel signal distribution to synchronize two independent BLDC controllers.

### 1. Signal Synchronization (Y-Splitter Method)
- **Throttle Signal**: A shielded 3-core Y-splitter cable sends the analog voltage signal (0.8V - 4.2V) from the handlebar throttle to both the Front and Rear BLDC controllers simultaneously.
- **Brake Cutoff**: NC (Normally Closed) or NO (Normally Open) e-brake sensors are connected in parallel to the high/low brake signal inputs of both controllers.
- **Display Connection**: The LCD display communicates via UART with the Master (Rear) controller for data logging, while the Slave (Front) controller operates on throttle signal only.

### 2. PAS (Pedal Assist) Integration
- **Primary Drive**: The 12-magnet PAS sensor is connected exclusively to the **Rear (Geared) Controller**.
- **Logic**: Pedal assist provides the initial torque for heavy loads. The front motor is used primarily for cruise and high-speed efficiency via manual throttle override.

## Firmware and Configuration
To ensure the two motors work in harmony rather than competing, the following firmware parameters are recommended:

### 1. Speed and Torque Matching
- **Speed Limit**: Matched to **25km/h (nominal)** on both controllers to prevent over-running.
- **Current Limit**:
  - Front (Direct Drive): **15A - 20A** (Optimized for cruise efficiency).
  - Rear (Geared): **22A - 30A** (Optimized for starting torque).

### 2. Acceleration Curves
- **Soft Start**: High setting (Level 5-10) to prevent wheel spin on the front 13\" car tire and reduce stress on the rear gears.
- **Regen Braking**: Enabled on the **Front Controller** only, set to 50% strength to provide stable slowing without skidding.

## Wiring Schematics (Simplified)
- **Main Bus**: 48V from dual batteries via 8AWG Equalizer.
- **Signal Bus**: 5V Hall effect, 5V PAS, 5V Throttle, and UART/CAN for display.
- **Connectors**: Use IP65 Julet/Higo connectors for all signal wiring to withstand industrial cleaning and weather.

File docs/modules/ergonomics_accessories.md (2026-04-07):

# Ergonomics and Accessories Module

The operator interface of the industrial bakfiets is designed for safety, adjustability, and comfort during heavy-duty operations.

## Operator Interface
### 1. Seating (Seat and Post)
- **Seat Post**: **31.6mm diameter** aluminum or steel post.
- **Seat Tube Clamp**: **QR (Quick Release) 34.9mm clamp**.
- **Saddle**: Wide, ergonomic industrial saddle with integrated coil spring suspension.

### 2. Steering & Control (Stem and Bars)
- **Handlebars**: 720mm - 780mm width steel riser or downhill (DH) bars for maximum leverage.
- **Stem**: **90mm Adjustable Stem** (0 to 60 degrees) or heavy-duty fixed stem.
- **Grips**: Double-lock-on rubber grips.

## Safety and Accessories
### 1. Lighting System (Lights and Horn)
- **Power Source**: Integrated **48V-to-12V DC-DC Converter**.
- **Headlights**: Dual **10W - 20W LED Floodlights** (IP67/IP69K).
- **Tail-light**: Integrated LED brake and tail-light.

### 2. Audio and Vision (Horn and Mirrors)
- **Horn**: 110dB - 120dB Industrial-grade horn (12V).
- **Mirrors**: Dual **100mm - 120mm Wide-angle Mirrors**.

## Mechanical Integration
### 1. Accessory Mounting
- **Lights**: Mounted using **M6 Grade 8.8 Bolts** to the cargo box steel angle skeleton.
- **DC-DC Converter**: Mounted inside the Rear BLDC Housing Box using **M4 screws**.

## Operation Methods
### Startup Procedure
1. Verify battery levels on the LCD display.
2. Check lighting and horn operation.
3. Ensure stabilizers are fully retracted and secured with hitch pins.
4. Perform a low-speed brake test.

## Tolerances and Fit
- **Seat Post Fit**: **Snug-Fit (0.1mm clearance)** in seat tube.
- **Handlebar Clamp**: Standard **31.8mm** interface.

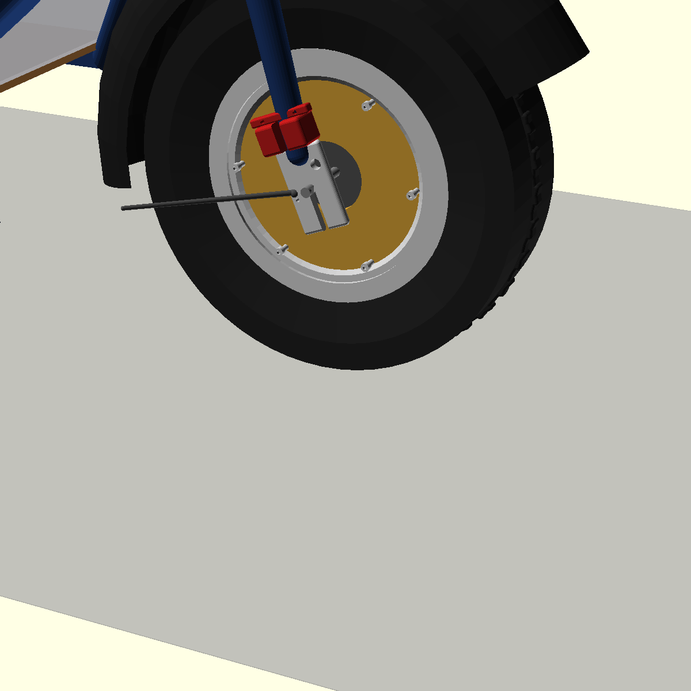
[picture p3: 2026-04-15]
docs/renders/final_iso.png

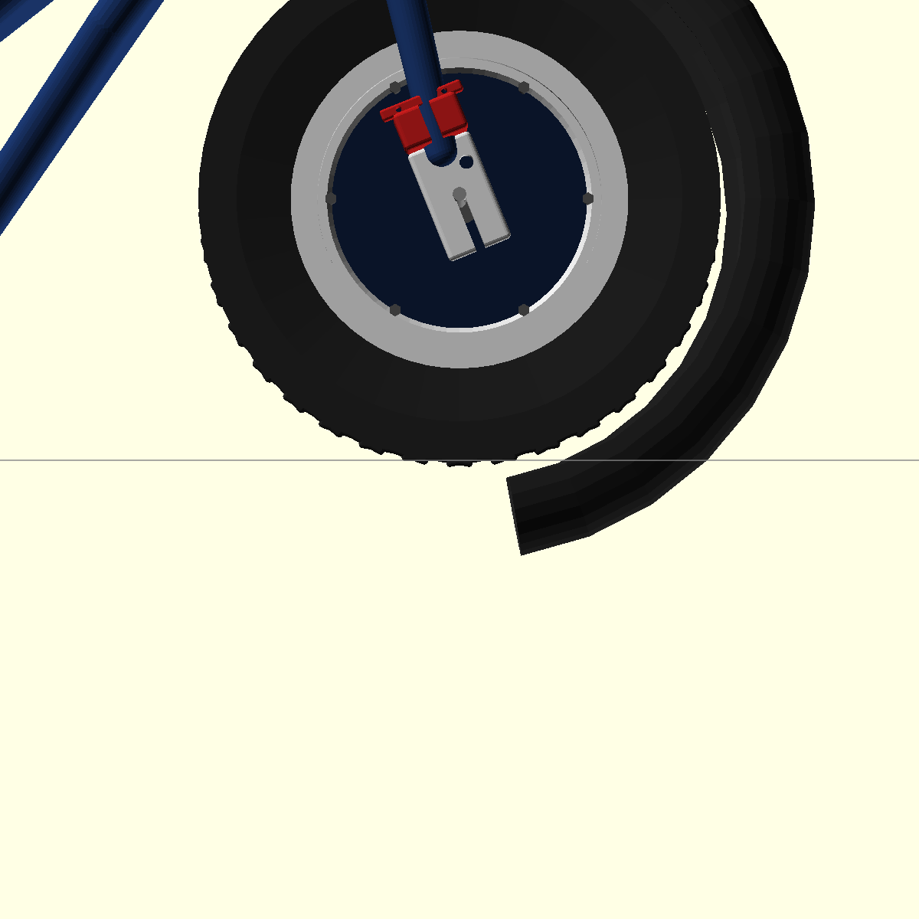
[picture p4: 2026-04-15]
docs/models/diag_full.png

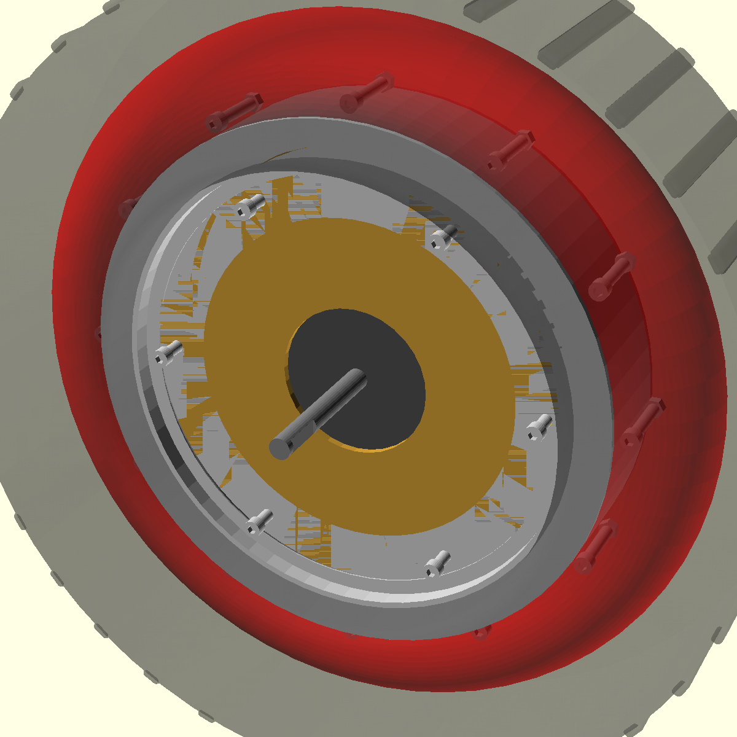
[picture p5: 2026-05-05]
docs/renders/front_wheel_xray.png

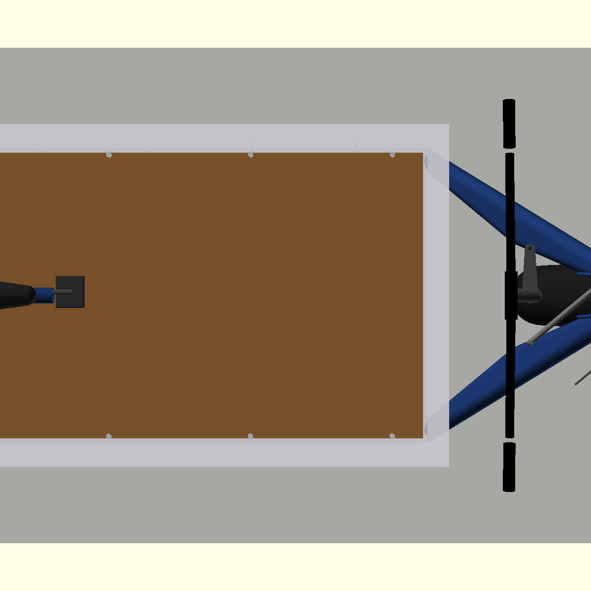
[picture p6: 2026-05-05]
docs/renders/final_top.png

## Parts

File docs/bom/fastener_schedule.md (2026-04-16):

# Fastener Schedule and Torque Specifications

This document provides a consolidated list of all fasteners required to assemble the Industrial E-Bakfiets. Using the specified grade is critical for structural safety.

## 1. Primary Structural Fasteners

| Location | Description | Grade | Qty | Torque |
| --- | --- | --- | --- | --- |
| **Front Wheel Rim** | M8 x 140mm SHCS | 10.9 | 6 | 30 Nm |
| **Front Motor Flange** | M5 x 20mm SHCS | 12.9 | 24 | 8 Nm |
| **Front Axle Nuts** | M14 x 1.5 Flange Nut | - | 2 | 50 Nm |
| **Torque Arm Anchor** | M8 x 30mm Hex Bolt | 10.9 | 1 | 25 Nm |
| **Steering Collars** | M5 x 8mm Cup Point Set Screw | 12.9 | 12 | 6 Nm |
| **Steering Linkage** | M10 x 1.5 Rod End Nut | 8.8 | 2 | 40 Nm |
| **Rear Axle Nuts** | M10/M12 Flange Nut | - | 2 | 40 Nm |

## 2. Secondary/Attachment Fasteners

| Location | Description | Grade | Qty | Notes |
| --- | --- | --- | --- | --- |
| **Brake Calipers** | M6 x 20mm Hex/SHCS | 10.9 | 4 | Use Blue Loctite |
| **Cargo Box Mount** | M10 x 50mm Hex Bolt | 8.8 | 8 | With large fender washers |
| **Electrical Enclosure** | M6 x 16mm Pan Head | SS | 8 | Stainless Steel |
| **Mudguard Crown** | M6 x 20mm SHCS | 10.9 | 2 | |
| **Mudguard Stays** | M5 x 12mm Button Head | 10.9 | 4 | |
| **Canopy Sockets** | M8 x 15mm Set Screw | 10.9 | 4 | For modular removal |

## 3. General Requirements
- **Nyloc Nuts**: All through-bolts must be secured with Nyloc (nylon-insert) locking nuts.
- **Washers**: Use heavy-duty, thick washers on all structural joints to prevent the bolt head from crushing the steel tubing.
- **Loctite**: Apply Medium Strength (Blue) thread locker to any fastener subject to motor or road vibration that does not use a Nyloc nut.

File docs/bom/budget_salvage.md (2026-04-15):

# BOM: Budget Salvage

This BOM is for a build that maximizes the use of salvaged bicycle and car parts, with a focus on affordability.

| Category | Component | Specification | Estimated Cost |
| --- | --- | --- | --- |
| **Front Wheel** | Car Tire | 155/70 R13 (salvaged) | $10 |
| | Split Rim | 13-inch steel split rim (salvaged) | $20 |
| | Front Hub Motor | 250W Direct Drive (salvaged) | $60 |
| **Rear Wheel** | Rear Rim | 16-inch Bicycle Rim (salvaged) | $0 |
| | Rear Hub Motor | 300W-500W Geared (salvaged) | $80 |
| **Frame** | Steel Tubing | 40x40x2mm steel (scrap/salvaged) | $20 |
| | Steering Bearings | Pair of 7202 Angular Contact (new) | $15 |
| | Stabilizer Screws | 4x M16 Threaded Rod (salvaged) | $10 |
| **Brakes** | Calipers/Rotors | Disc Brake set (salvaged) | $30 |
| **Electrical** | Batteries | 2x 36V/48V 10Ah (salvaged) | $250 |
| | Controllers | Dual 36V/48V 15A BLDC (salvaged) | $40 |
| | DC-DC / Wire | 48V-12V DC-DC + Equalizer Wire | $25 |
| **Lighting/Safe** | Lights/Horn | Salvaged car/moped lights + horn | $15 |
| **Ergonomics** | Seat/Stem/Bars | Salvaged bike parts | $0 |
| **Cargo Box** | Box Materials | Salvaged plywood + steel angle | $20 |
| **Fasteners** | Structural | Assorted M8/M10 (salvaged/new) | $20 |
| | Misc | Cable ties + basic tubing | $10 |
| **Total** | | | **~$625** |

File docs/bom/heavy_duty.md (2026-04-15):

# BOM: Heavy Duty

This BOM is for a build that is over-engineered for maximum cargo capacity, with a focus on durability and power.

| Category | Component | Specification | Estimated Cost |
| --- | --- | --- | --- |
| **Front Wheel** | Car Tire | 155/70 R13 (Heavy Duty) | $60 |
| | Split Rim | 13-inch steel split rim (5mm steel) | $75 |
| | Front Hub Motor | QS Motor 205 (50H) V3 Hub Motor | $450 |
| | Motor Adapters | 2x 15mm Stainless Steel plates (Laser-cut) | $120 |
| **Rear Wheel** | Rear Rim | 16-inch Steel Moped Rim (MZ ETZ type) | $80 |
| | Rear Hub Motor | 500W-800W Geared or Direct Drive | $300 |
| | Rear Tire | 110/80-16 rugged moped tire | $60 |
| **Frame** | Steel Tubing | 50x25x3mm rectangular steel | $130 |
| | Steering Bearings | Pair of 7202 Angular Contact (High Load) | $30 |
| | Stabilizer Screws | 4x M20x300mm Threaded Rod (Grade 10.9) | $40 |
| **Brakes** | Front Caliper | Hydraulic 4-piston (Magura MT5) | $120 |
| | Rear Caliper | Hydraulic 2-piston (Shimano MT200) | $60 |
| | Rotors | 1x 203mm Front, 1x 180mm Rear (2.0mm thick) | $80 |
| **Electrical** | Batteries | 2x 48V/60V 20Ah LiFePO4 | $900 |
| | Controllers | Dual 48V/60V 25-35A BLDC | $150 |
| | DC-DC Converter | 48V-12V 20A Industrial | $40 |
| | Equalizer Wire | 3m of 8AWG Silicone + XT90-S | $40 |
| **Lighting/Safe** | Headlights | Dual 20W LED Floodlights (IP69K) | $60 |
| | Horn/Mirrors | 120dB Horn + Dual 120mm Mirrors | $50 |
| **Ergonomics** | Seat/Post | Suspension Post + Gel Saddle | $80 |
| | Stem/Bars | Heavy Duty Stem + 780mm DH Bars | $70 |
| **Cargo Box** | Panels | 15mm Marine Plywood / Aluminum | $150 |
| | Reinforcement | 6m of 30x30x3mm Steel Angle | $50 |
| | Anchor Points | 6x heavy-duty tie-downs | $30 |
| **Fasteners** | Structural | Grade 12.9 fastener assortment (M8x140, M14) | $80 |
| | Cable Mgmt | Braided Sleeving + SS Cable Ties | $60 |
| **Total** | | | **~$3,275** |

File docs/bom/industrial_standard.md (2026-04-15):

# BOM: Industrial Standard

This BOM is for a build using primarily new industrial and bicycle components, balancing cost with reliability.

| Category | Component | Specification | Estimated Cost |
| --- | --- | --- | --- |
| **Front Wheel** | Car Tire | 155/70 R13 (new) | $40 |
| | Split Rim | 13-inch steel industrial split rim (6-bolt PCD 260) | $50 |
| | Front Hub Motor | Golden Motor Magic Pie 5 (Fatbike 190mm Axle) | $320 |
| | Motor Adapters | 2x 12mm Steel/Brass plates (laser-cut, 330mm OD) | $80 |
| | Torque Arm | 10mm steel laser-cut plate | $25 |
| **Rear Wheel** | Rear Rim | 16-inch Steel Moped Rim (MZ ETZ 150/251 type) | $50 |
| | Rear Hub Motor | 350W-500W Geared (36V/48V, 135mm) | $180 |
| | Rear Tire | 16x2.50 or 3.50-16 rugged tire | $40 |
| **Frame** | Steel Tubing | 40x40x2.5mm rectangular + 1-1/4\" Sch 40 Pipe | $90 |
| | Steering Shaft | 15mm x 500mm Precision Steel Rod | $20 |
| | Steering Bearings | Pair of 7202 Angular Contact (15x35x11) | $20 |
| | Stopping Elements | 35mm OD steel collars (machined/laser-cut) | $15 |
| | Stabilizer Tubing | 1m 35x35x2.5mm + 1m 25x25x2.5mm (Square) | $20 |
| | Stabilizer Screws | 4x M16x250mm Threaded Rod (Grade 8.8) | $20 |
| **Brakes** | Front Caliper | Hydraulic 4-piston (PM mount) | $60 |
| | Rear Caliper | Hydraulic/Mechanical (IS mount) | $40 |
| | Rotors | 1x 203mm Front, 1x 180mm Rear (6-bolt) | $45 |
| **Electrical** | Batteries | 2x 48V 10Ah LiFePO4 | $400 |
| | Controllers | Dual 36V/48V 15-22A BLDC (Sinewave) | $80 |
| | DC-DC / Wiring | 48V-12V Converter + Equalizer + PA6 Tubing | $70 |
| | Housing Boxes | 2x Oversized Waterproof Enclosures | $40 |
| **Lighting/Safe** | Lighting/Horn | Dual 10W LED + 110dB Horn + Mirrors | $55 |
| **Ergonomics** | Seat/Stem/Bars | 31.6mm Post + Adjustable Stem + 720mm Bars | $85 |
| **Cargo Box** | Panels/Steel | 12mm Marine Plywood + 25x25mm Steel Angle | $110 |
| | Logistics Rails | 2m E-track (zinc plated steel) | $35 |
| | Anchor Points | 4x D-ring rated for 250kg | $15 |
| **Fasteners** | Structural | Grade 10.9 structural assortment (M8x50, M10, M14) | $45 |
| **Total** | | | **~$1,975** |

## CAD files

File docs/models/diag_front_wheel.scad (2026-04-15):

include <master_dims.scad>
include <parts.scad>
include <front_wheel_assy.scad>

// Cross section to see the interface
difference() {
    front_wheel_assy();
    translate([0, 500, 0]) cube([1000, 1000, 1000], center=true);
}

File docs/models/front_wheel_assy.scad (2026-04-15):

include <master_dims.scad>
include <parts.scad>

// COMPLETE FRONT WHEEL ASSEMBLY
// Origin = Axle Center (0,0,0)
module front_wheel_assy() {
    car_tire_13in();
    car_rim_13in_split();
    rim_fastener_pattern();
    hub_motor_dd();
}

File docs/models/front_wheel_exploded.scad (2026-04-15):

include <master_dims.scad>
include <parts.scad>

// FRONT WHEEL - EXPLODED VIEW
// Origin = Axle Center (0,0,0)
module front_wheel_exploded(gap=100) {

    // 1. Central Motor
    hub_motor_dd();

    // 2. Adapters
    for(s=[-1, 1]) translate([0, s * (50 + gap), 0]) rotate([90, 0, 0])
    color(color_brass)
    difference() {
        cylinder(d=motor_flange_od, h=motor_flange_t, center=true);
        cylinder(d=100, h=motor_flange_t+1, center=true);
        for(a=[0:60:359]) rotate([0, 0, a]) translate([rim_bolt_pcd/2, 0, 0]) cylinder(d=8.5, h=30, center=true);
        for(a=[0:30:359]) rotate([0, 0, a]) translate([front_hub_flange_dia/2 - 10, 0, 0]) cylinder(d=5.5, h=30, center=true);
    }

    // 3. Rim Halves
    for(s=[-1, 1]) translate([0, s * (50 + gap * 2), 0])
    if (s==1) car_rim_half(); else mirror([0,1,0]) car_rim_half();

    // 4. Tube (Centered, slightly expanded)
    car_tube_13in();

    // 5. Tire (Cutaway or offset)
    translate([0, gap * 3, 0])
    car_tire_13in(alpha=0.4);

    // 6. Fasteners
    rim_fastener_pattern(exploded=gap/50);
}

front_wheel_exploded(80);

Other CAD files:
docs/models/front_wheel_verify.scad
docs/models/diag_fork.scad
docs/models/diag_frame.scad
docs/models/diag_front_end.scad
docs/models/diag_tire.scad
docs/models/ebakfiets_parts.scad
docs/models/frame.scad
docs/models/front_fork.scad
docs/models/front_wheel/wheel_155_75_r13.scad
docs/models/front_wheel_xray.scad
docs/models/full_assembly.scad
docs/models/master_dims.scad
docs/models/parts.scad
docs/models/parts_bugs.scad
docs/models/steering_head.scad

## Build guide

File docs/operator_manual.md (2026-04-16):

# Operator's Manual: Industrial E-Bakfiets

Welcome to your heavy-duty cargo vehicle. This manual covers the basic operation, safety limits, and best practices for the Industrial E-Bakfiets.

## 1. Safety Information
- **Maximum Payload**: 350kg (Cargo only).
- **Maximum Speed**: 25km/h (Assisted).
- **Braking**: Always use both front and rear brakes. The front brake provides ~70% of stopping power.
- **Center of Gravity**: Place heavy items at the bottom of the cargo box, centered between the side spars.

## 2. Startup Procedure
1. **Check Tires**: Ensure front tire is firm (45 psi).
2. **Power On**: Turn on both battery packs (or the master switch).
3. **Monitor Check**: Observe the Supervisory Controller display. Verify battery voltage is >42.0V.
4. **Throttle Test**: Gently blip the throttle to confirm both motors are responding.

## 3. Riding with Cargo
- **Starting**: Use the rear geared motor (pedal assist or gentle throttle) to get moving. The front motor is most efficient once you are at a walking pace.
- **Cornering**: Slow down before turns. The long 1950mm wheelbase requires wider turning circles than a standard bicycle.
- **Climbing**: For steep hills, maintain a steady cadence and allow the geared rear motor to provide the bulk of the torque.

## 4. Charging
- Use the provided dual-output or two separate chargers.
- Charge in a well-ventilated area.
- Do not leave the batteries charging unattended for more than 12 hours.

## 5. Emergency Procedures
- **Electrical Cutoff**: If the throttle sticks, pull either brake lever; the built-in cutoff sensors will kill power to both motors.
- **Overheat Alarm**: If the Supervisory Controller buzzes, slow down or stop and allow the motors to cool. This typically occurs only during prolonged heavy climbing in hot weather.

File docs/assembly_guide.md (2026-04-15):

# Assembly Guide: Industrial E-Bakfiets

This guide outlines the recommended sequence for assembling the Industrial E-Bakfiets. It assumes all custom parts (frame, fork, adapters) have been fabricated according to the specifications in the `docs/modules/` and `docs/drawings/` folders.

## Phase 1: Frame and Fork Preparation
1. **Deburring**: Ensure all laser-cut edges and tube ends are deburred.
2. **Head Tube**: Press the 7202 Angular Contact bearings into the steering head.
3. **Alignment Check**: Ensure the rear dropouts are parallel (135mm spacing) and the front fork crown is square to the steering axis.
4. **Painting**: Apply industrial-grade powder coating or anti-corrosive primer and paint.

## Phase 2: Front Wheel & Hub Assembly
1. **Motor Adapters**: Bolt the 12mm adapter plates to the Golden Motor Magic Pie 5 spoke flanges using 24x M5x20mm Grade 12.9 bolts (12 per side). Use Blue Loctite.
2. **Rim Sandwich**: Place the 13-inch tire and tube between the two rim halves. Sandwich this assembly between the two adapter plates.
3. **Fastening**: Pass the 6x M8x140mm Grade 10.9 bolts through the entire assembly. Tighten in a star pattern to **30Nm**.
4. **Disc Rotor**: Install the 203mm rotor using M5 bolts (6-bolt ISO).

## Phase 3: Steering and Cockpit
1. **Steering Shaft**: Slide the 15mm shaft through the head tube bearings. Secure with the 35mm OD locking collars.
2. **Handlebars**: Install the adjustable stem and 720mm bars.
3. **Linkage**: Connect the steering bell cranks using the 15mm tie-rod and M10 rod ends. Adjust for zero toe-in.

## Phase 4: Drivetrain and Brakes
1. **Bottom Bracket**: Install the square-taper BB and 170mm cranks.
2. **Rear Wheel**: Install the 16-inch geared hub motor wheel into the rear dropouts.
3. **Chain**: Route the chain through the derailleur. Ensure proper tensioning.
4. **Braking**: Mount the hydraulic calipers. Bleed the lines and ensure the 203mm (front) and 180mm (rear) rotors have centered clearance.

## Phase 5: Electrical Integration
1. **Battery Mount**: Secure the dual LiFePO4 packs under the cargo bed spars using heavy-duty straps or custom enclosures.
2. **Controllers**: Mount the front and rear controllers in the waterproof enclosures.
3. **Wiring**: Route the main 48V bus and the signal Y-splitter. Use spiral wrap or PA6 tubing for protection.
4. **Supervisory Controller**: (Optional) Install the ESP32/Arduino system monitor in the cockpit.

## Phase 6: Final Commissioning
1. **Static Test**: Check all bolt torques (especially M14 axle nuts and M8 rim bolts).
2. **Power Up**: Test throttle response on a bike stand (wheels off ground).
3. **Brake Test**: Ensure e-brake cutoffs function on both motors.
4. **Load Test**: Perform a low-speed test ride with 50kg of cargo to check for frame flex or linkage binding.

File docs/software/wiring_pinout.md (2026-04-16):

# Supervisory Controller: Wiring and Pinout Specification

This document details the precise wiring for the Arduino/ESP32 based Supervisory Controller used in the Industrial E-Bakfiets.

## 1. Microcontroller Pin Mapping (Arduino Nano Reference)

| Pin | Function | Type | Connection |
| --- | --- | --- | --- |
| **A0** | Battery Voltage | Analog In | 60V Voltage Divider (10k/1k) |
| **A1** | Front Current | Analog In | ACS758 Sensor (Front Controller V+) |
| **A2** | Rear Current | Analog In | ACS758 Sensor (Rear Controller V+) |
| **A3** | Front Motor Temp | Analog In | NTC 10k Thermistor (Motor Hub) |
| **A4** | Rear Motor Temp | Analog In | NTC 10k Thermistor (Motor Hub) |
| **A5** | I2C SCL | Digital | 20x4 LCD Display |
| **A6** | I2C SDA | Digital | 20x4 LCD Display |
| **D9** | Alarm Buzzer | PWM Out | 5V Active Buzzer / Piezo |
| **D10** | Throttle Cutoff | Digital Out | Relay/Optocoupler (Intercepts 5V signal) |
| **VIN** | Power In | Power | 12V DC-DC Converter Bus |
| **GND** | Ground | Power | Main System Ground |

## 2. Sensor Calibration Data
- **Voltage Divider**: $V_{out} = V_{in} \times (1000 / (10000 + 1000))$. Multiply raw reading by **11.0**.
- **Current Sensor (ACS758-50B)**: 40mV per Amp. Zero point at 2.5V.
- **Thermistor**: Use 10k pull-up resistor. Beta value: 3950.

## 3. Signal Harness Color Code (Recommended)
| Color | Function | Gauge |
| --- | --- | --- |
| **Red** | 12V DC-DC Power | 20 AWG |
| **Black** | Signal Ground | 20 AWG |
| **Yellow** | Analog Data (V/A/T) | 22 AWG |
| **Green** | I2C SDA | 24 AWG (Twisted Pair) |
| **Blue** | I2C SCL | 24 AWG (Twisted Pair) |
| **White** | Alarm/Control | 22 AWG |

## 4. Interference Mitigation
- **Shielding**: The Analog signal wires (A1-A4) should be routed through a grounded braided copper sleeve to prevent noise from the BLDC phase wires.
- **Capacitance**: Add a 0.1uF capacitor between each Analog Input and GND at the Arduino pins to filter high-frequency switching noise.

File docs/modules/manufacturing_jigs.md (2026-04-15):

# Manufacturing Jigs and Alignment Module

Building a precise industrial frame requires specialized jigs to ensure all components are aligned within engineering tolerances.

## Frame Jig Design
### 1. Main Base (The "Reference Table")
- **Material**: Flat steel plate (10mm thick) or a heavy-duty level wooden workbench reinforced with steel channels.
- **Size**: At least 1000mm x 2500mm.
- **Grid**: Mark a centerline and 100mm grid lines across the entire surface using a scribe or permanent marker.

### 2. Spar Alignment Guides
- **Components**: **50x50x5mm Steel Angle Iron** sections (approx. 200mm long) bolted or clamped to the base plate.
- **Function**: These guides lock the two main 40x40mm spars in a perfectly parallel position.
- **Setup**: Position the inner faces of the guides at exactly **834mm** apart to match the required cargo bed exterior width.

### 3. Head Tube V-Block & Riser Jig
- **Material**: Machined steel V-block or a "V" notch cut into 40x40mm tubing.
- **Angle Support**: A vertical 40x40mm pillar welded to the base plate at the front. Use an adjustable brace to lock the V-block at **68 degrees** relative to the base table.
- **Elevation**: The center of the V-block must be held **650mm** above the base table to accommodate the "Gooseneck" riser geometry.

### 4. Steering Hub Dummy Axle
- **Tool**: A 15mm precision rod (stepped to 12mm or 10mm if needed).
- **Function**: Insert through the head tube during welding to ensure the tube doesn't warp and that the steering axis remains perfectly collinear.

## Alignment Techniques
### 1. Dropout Squareness
- **Method**: Use a **135mm precision spacer** (dummy axle) clamped in the rear dropouts during welding to prevent warping and ensure the axle sits perpendicular to the frame spars.

### 2. Centering the Steering Column
- **Method**: Use a plumb line or laser level from the head tube center to the midpoint of the rear dropout spacer.
- **Tolerance**: The front and rear wheel tracks must be aligned within **+/- 2mm**.

### 3. Cargo Bed Flatness
- **Method**: Check diagonal measurements corner-to-corner on the 1350mm x 810mm bed spars.
- **Tolerance**: Corner-to-corner difference should not exceed **3mm**.

## Assembly Tips
- **Tack Welding**: Always tack weld the entire frame (at least 4 points per joint) while in the jig before performing final structural welds.
- **Heat Management**: Weld in short (20mm) sections, alternating between left and right sides of the frame to prevent the 1950mm rails from "bowing" during cooling.
- **Squareness Check**: Before final welding, measure the diagonals of the cargo bed ($A-C$ and $B-D$). They must be within **2mm** of each other.
- **Post-Weld Inspection**: After cooling, verify that the 7202 bearings slip into the head tube. If the tube has shrunk slightly, use a 35mm adjustable reamer to restore the bearing seat.

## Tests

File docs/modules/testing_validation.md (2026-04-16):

# Testing and Validation Module

To ensure the Industrial E-Bakfiets meets its heavy-duty performance targets safely, the following testing protocols must be followed after assembly and before commissioning for cargo use.

## 1. Static Load Testing
Verify the structural integrity of the frame and cargo bed.
- **Protocol**: Gradually load the cargo bed with sandbags or weighted plates up to **350kg**.
- **Observation**: Check for visible deflection in the 40x40mm main spars. Deflection at the center of the bed should not exceed **5mm**.
- **Weld Inspection**: Inspect all critical weldments (Header plate, Gooseneck, Dropouts) for hairline cracks or paint flaking using a magnifying glass.

## 2. Dynamic Braking Test
Verify the stopping power of the 203mm/180mm hydraulic brake system.
- **Protocol**: With a **100kg** test load, accelerate to **20km/h** and perform an emergency stop.
- **Requirement**: The vehicle must come to a complete stop within **4.5 meters** on dry pavement.
- **Brake Fade**: Repeat 5 times in rapid succession. Check for lever "sponginess" or significant reduction in stopping power.

## 3. Steering and Linkage Validation
Ensure the dual bell crank system is reliable and binding-free.
- **Protocol**: Perform a "Full-Lock-to-Lock" test while stationary with a 100kg load in the box.
- **Observation**: Listen for clicking or grinding in the 7202 bearings. Verify that the steering tie-rod does not contact the frame or cargo box at any point in the 90-degree total sweep.
- **Centering**: Ride in a straight line at 10km/h. Release the handlebars momentarily (if safe) to verify the vehicle does not pull to one side.

## 4. Electrical Stress Test
Verify the thermal management and power delivery of the dual-motor system.
- **Protocol**: Navigate a **10% grade** hill for at least 500 meters with a 150kg total load.
- **Monitoring**: Use the Supervisory Controller to monitor motor temperatures.
- **Threshold**: Neither motor should exceed **75°C** during this climb.
- **Redundancy Test**: Temporarily disconnect the front motor. Verify the rear geared motor can initiate a hill-start under load without stalling or excessive overheating.

## 5. Vibration and Hardware Audit
- **Protocol**: Ride over a 50-meter section of "cobblestone" or rough gravel.
- **Inspection**: Immediately re-torque the **M8x140mm Rim Bolts** and **M14 Axle Nuts**. If any have loosened, apply high-strength thread locker and re-test.

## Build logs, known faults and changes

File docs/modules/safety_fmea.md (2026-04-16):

# Failure Mode and Effects Analysis (FMEA)

This document identifies potential failure points in the Industrial E-Bakfiets design and specifies the engineering mitigations implemented to reduce risk.

| System | Potential Failure Mode | Effect | Severity | Mitigation Strategy |
| --- | --- | --- | --- | --- |
| **Steering** | Tie-rod end shear or detachment | Loss of steering control | **High** | Use of M10 Chrome-moly rod ends; Dual roll-pins on shaft collars; Redundant locking nuts. |
| **Frame** | Gooseneck weld fatigue | Structural collapse under load | **High** | Oversized 40x40mm tubing with internal gussets; Tapered "Gooseneck" geometry to distribute stress. |
| **Front Wheel** | M8 Rim Bolt loosening | Rim separation/Tube blowout | **High** | Grade 10.9 fasteners; Star-pattern torque spec (30Nm); Required use of Nyloc nuts and Blue Loctite. |
| **Electrical** | Battery thermal runaway | Fire hazard | **High** | LiFePO4 chemistry (inherently safer); Isolated waterproof enclosures; MIDI fuse protection (40A). |
| **Motor** | Axle rotation (Torque spin) | Phase wire shear; Motor loss | **Medium** | 10mm thick Grade 43 steel torque arm with dual-point anchoring to fork leg. |
| **Brakes** | Hydraulic line rupture | Partial loss of braking | **Medium** | Independent front/rear systems (203mm/180mm); Steel-braided hoses recommended for industrial use. |
| **Drivetrain** | Chain derailment | Loss of pedal assist | **Low** | Use of HDPE chain tubes to maintain alignment; High-engagement chainring profile. |

## Critical Inspection Points
For fleet operators, the following three items are considered **"Mission Critical"** and must be inspected daily:
1. **Steering Shaft Play**: Any vertical or radial play indicates bearing or collar failure.
2. **Torque Arm Bolt**: Ensure the M8 anchor bolt is tight and the arm shows no deformation.
3. **Rim Bolt Visual**: Check for any gap between the two rim halves or the adapter flanges.

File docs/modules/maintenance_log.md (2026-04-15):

# Maintenance and Fleet Management Log

The Industrial E-Bakfiets is designed for heavy usage. This log provides a framework for periodic inspections and preventative maintenance.

## 1. Maintenance Schedule

| Interval | Component | Action | Specification |
| --- | --- | --- | --- |
| **Daily** | Brakes | Check lever feel and pad contact | 203mm rotor check |
| | Tires | Check pressure (Front: 45psi, Rear: 35psi) | Visual check for cuts |
| | Battery | Charge to 100% and balance | 54.6V (48V pack) |
| **Weekly** | Chain | Clean and lubricate | Industrial wet-lube |
| | Fasteners | Torque check Axle Nuts and Rim Bolts | M14: 50Nm, M8: 30Nm |
| | Steering | Check for play in rod ends | Zero play required |
| **Monthly** | Bearings | Inspect 7202 Steering bearings | Re-grease if gritty |
| | Spokes | Pluck test for tension (Rear 16") | 10G heavy spokes |
| | Wiring | Check for insulation abrasion | Inspect PA6 conduits |
| **6-Months** | Hub Motors | Check for moisture/rust on flanges | Apply anti-corrosive |
| | Brake Fluid | Check level and color | Mineral Oil / DOT 4 |

## 2. Maintenance Log Template

**Vehicle ID:** _________  **Odometer/Hours:** _________  **Date:** _________

| System | Condition (OK/Fix) | Notes |
| --- | --- | --- |
| Front Hub Assembly | | |
| Steering Linkage | | |
| Main Frame Weldments | | |
| Brake Pads/Rotors | | |
| Battery Health (V) | | |
| Tire Tread Depth (mm) | | |

**Technician Signature:** ____________________

## 3. Industrial Spare Parts Kit
It is recommended for fleet operators to keep the following in stock:
- 2x M8x140 Grade 10.9 Rim Bolts.
- 1x Set of 203mm Brake Pads.
- 1x Spare 13-inch Car Inner Tube.
- 1x M10 LH/RH Rod End set.
- 1x Pair of 7202 Angular Contact Bearings.

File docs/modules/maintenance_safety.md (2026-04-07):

# Maintenance and Safety Module

To ensure the long-term reliability and safety of the industrial bakfiets under maximum cargo loads, a strict maintenance and operational protocol is required.

## Safety Protocols
### 1. Heavy Cargo Handling
- **Load Distribution**: Always place the heaviest items at the bottom and center of the cargo box.
- **Stabilization**: Engage all four corner stabilizer feet before loading or unloading using a forklift.
- **Maximum Load**: 350kg (Total vehicle + cargo + operator should not exceed 500kg).

### 2. Operational Safety
- **Startup**: Always power on the master controller first and verify brake cutoff functionality before motion.
- **Braking**: Rely on the front 203mm hydraulic brake as the primary stopping power, using the rear 180mm brake for control.
- **Speed**: Do not exceed 25km/h when fully loaded.

## Preventative Maintenance (PM) Schedule
| Interval | Component | Action |
| --- | --- | --- |
| **Daily** | Brakes | Test lever pressure and motor cutoff switches. |
| | Tires | Inspect for punctures and check pressure (3.5-4.0 bar). |
| | Battery | Check state of charge and ensure equalizer connection is tight. |
| **Weekly** | Fasteners | Check torque on M14 axle nuts and M8 rim bolts. |
| | Chain | Clean and lubricate industrial-grade chain. |
| | Cables | Inspect corrugated tubing and spiral wraps for rub points. |
| **Monthly** | Steering | Check M10 rod ends for play and lubricate if necessary. |
| | Controllers | Inspect housing boxes for moisture ingress. |
| **Quarterly** | Bearings | Inspect 7202 steering bearings and 6202 hub bearings for smoothness. |
| | Frame | Inspect weld points on main spars and cargo bed for stress cracks. |

## Build Checklist (Final Verification)
- [ ] All fasteners are Grade 8.8 or higher and tightened to specified torque.
- [ ] Stabilizer legs extend and retract smoothly with a cordless drill.
- [ ] 13\" car tire is correctly seated in the split rim.
- [ ] Wiring is fully protected in PA6 conduit and routed away from the chain line.
- [ ] PAS sensor triggers rear motor and throttle triggers both motors.

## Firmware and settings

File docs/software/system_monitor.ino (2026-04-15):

/*
 * Industrial E-Bakfiets: Supervisory Controller (Reference Implementation)
 *
 * Target: Arduino Nano / ESP32
 * Function: Monitors dual-motor current, temperatures, and battery SOC.
 * Displays data on a 20x4 I2C LCD for the operator.
 */

#include <Wire.h>
#include <LiquidCrystal_I2C.h>

// Pin Definitions
const int PIN_BATTERY_V = A0;  // 0-60V via Voltage Divider (10k/1k)
const int PIN_FRONT_CURR = A1; // 0-50A via Shunt (ASC712 or similar)
const int PIN_REAR_CURR  = A2;
const int PIN_FRONT_TEMP = A3; // NTC 10k Thermistor in motor housing
const int PIN_REAR_TEMP  = A4;
const int PIN_ALARM_BUZZER = 9;

// Calibration Constants
const float VOLT_DIVIDER_RATIO = 11.0; // (10k+1k)/1k
const float AMPS_PER_VOLT = 20.0;      // Calibration for current sensor
const int TEMP_THRESHOLD = 85;         // Max Celsius before alarm

// Global State
float batVoltage = 0;
float frontAmps = 0;
float rearAmps  = 0;
int frontTemp = 0;
int rearTemp  = 0;

LiquidCrystal_I2C lcd(0x27, 20, 4);

void setup() {
  Serial.begin(9600);
  lcd.init();
  lcd.backlight();
  pinMode(PIN_ALARM_BUZZER, OUTPUT);

  lcd.setCursor(0,0);
  lcd.print("E-BAKFIETS SYSTEM");
  lcd.setCursor(0,1);
  lcd.print("BOOTING V1.0...");
  delay(1000);
}

void loop() {
  readSensors();
  checkSafety();
  updateDisplay();
  delay(500);
}

void readSensors() {
  // Battery Voltage
  int rawV = analogRead(PIN_BATTERY_V);
  batVoltage = (rawV * (5.0 / 1023.0)) * VOLT_DIVIDER_RATIO;

  // Currents
  frontAmps = (analogRead(PIN_FRONT_CURR) - 512) * (5.0 / 1023.0) * AMPS_PER_VOLT;
  rearAmps  = (analogRead(PIN_REAR_CURR) - 512) * (5.0 / 1023.0) * AMPS_PER_VOLT;

  // Temperatures (Simplistic Linear Approximation for NTC)
  frontTemp = map(analogRead(PIN_FRONT_TEMP), 0, 1023, 20, 150);
  rearTemp  = map(analogRead(PIN_REAR_TEMP), 0, 1023, 20, 150);
}

void checkSafety() {
  if (frontTemp > TEMP_THRESHOLD || rearTemp > TEMP_THRESHOLD) {
    digitalWrite(PIN_ALARM_BUZZER, HIGH);
    lcd.setCursor(0,3);
    lcd.print("!! OVERHEAT ALARM !!");
  } else {
    digitalWrite(PIN_ALARM_BUZZER, LOW);
  }
}

void updateDisplay() {
  lcd.clear();
  // Row 0: Battery
  lcd.setCursor(0,0);
  lcd.print("BAT: "); lcd.print(batVoltage, 1); lcd.print("V ");
  lcd.print((batVoltage > 48) ? "HIGH" : "LOW");

  // Row 1: Front Motor
  lcd.setCursor(0,1);
  lcd.print("FR: "); lcd.print(frontAmps, 1); lcd.print("A ");
  lcd.print(frontTemp); lcd.print("C");

  // Row 2: Rear Motor
  lcd.setCursor(0,2);
  lcd.print("RR: "); lcd.print(rearAmps, 1); lcd.print("A ");
  lcd.print(rearTemp); lcd.print("C");

  // Row 3: Total Power
  float totalPower = batVoltage * (frontAmps + rearAmps);
  lcd.setCursor(0,3);
  lcd.print("PWR: "); lcd.print(totalPower, 0); lcd.print("W");
}

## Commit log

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2026-04-05 Improve industrial e-bakfiets design with precise dimensions and tolerances
    - Added specific dimensions and engineering tolerances to all project modules.
    - Updated Front Wheel Module with 180mm fork width and 175mm motor dropout specifications.
    - Defined Frame Module with 1210mm x 810mm internal bed dimensions for standard Euro-pallet compatibility.
    - Enhanced Electrical Module with 40-50A BMS requirements and battery enclosure dimensions.
    - Refined Brakes & Steering Module with 180-203mm rotor specs and M10/M12 rod end clearances.
    - Improved all BOM configurations with specific part standards and power/current ratings.
    - Created a design verification tool to ensure dimensional consistency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
2026-04-05 Expand industrial e-bakfiets design with modular docs, alternative BOMs, and technical specs
    - Refactored project into five technical modules: Front Wheel, Frame, Electrical, Drivetrain, and Brakes/Steering.
    - Developed three alternative Bill of Materials (BOM) files: Budget Salvage, Industrial Standard, and Heavy Duty.
    - Added comprehensive dimensions and engineering tolerances (e.g., 180mm fork width, 1210x810mm cargo bed).
    - Ensured all BOM components are detailed in module documentation using custom audit tools.
    - Verified mechanical fit and clearances (e.g., tire-to-fork, chain-line) with a design verification tool.
    - Preserved the original project description as README_ORIGINAL.md and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
2026-04-05 Finalize industrial e-bakfiets design with modular docs, BOMs, and verified technical specs
    - Refactored project into five technical modules: Frame, Front Wheel, Drivetrain, Electrical, and Brakes/Steering.
    - Added comprehensive engineering dimensions, tolerances, and fit classes (Loose, Snug, Press, Wide).
    - Verified mechanical integrity, shaft fits, and clearances (e.g., tire-to-fork, axle-to-dropout) using custom design verification tools.
    - Ensured all BOM components are documented in modules using a custom audit tool.
    - Preserved the original project description as README_OR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
2026-04-05 Finalize industrial e-bakfiets design with modular docs, BOMs, and verified technical specs
    - Defined precise mechanical integration for bearings and shafts, including press-fit (e.g., EC34 headset) and clearance-fit specifications.
    - Added step-by-step assembly and disassembly methods for all subsystems.
    - Verified mechanical integrity, shaft fits, and clearances (e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
2026-04-05 Redesign industrial e-bakfiets steering using 7202 bearings and non-machined pipe assembly
    - Replaced EC34 headset with a pair of 7202 angular contact bearings (15x35x11mm).
    - Redesigned head tube using 1-1/4" Schedule 40 steel pipe (ID ~35.05mm) for a no-machining slip-fit.
    - Implemented a 6-hole radial pattern and M5 locking screws to secure internal bearing stopping collars.
    - Selected 15mm precision steel rod for the inner steering shaft to match bearing bore.
    - Updated all module documentation (Frame, Brakes/Steering) with the new mechanical integration details.
    - Revised BOM configurations (Budget, Standard, Heavy Duty) to reflect the new steering hardware.
    - Verified all new mechanica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
2026-04-06 Finalize industrial e-bakfiets design with modular docs, BOMs, and verified technical specs
    - Redesigned the steering head using 7202 angular contact bearings and 1-1/4" Sch 40 pipe (ID ~35.05mm) for a no-machining assembly.
    - Implemented a decentralized electrical system with dual batteries and controllers placed near their motors, linked by thick 8AWG equalizer wir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
2026-04-06 Finalize industrial e-bakfiets design with 16-inch rear wheel and modular docs
    - Redesigned the rear wheel system to 16-inch diameter for increased motor torque and lower center of gravity.
    - Integrated MZ ETZ 150/251 moped steel rims as the recommended heavy-duty rear wheel option.
    - Provided alternative 16-inch bicycle and e-bike wheel options for build flexibility.
    - Added comprehensive engineering dimensions, tolerances, and fit classes (Loose, Snug, Press, Wide)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
2026-04-06 Finalize industrial e-bakfiets design with cargo stabilizers and modular docs
    - Implemented a four-corner cargo bed stabilizer system using telescopic square steel tubing (35x35mm/25x25mm).
    - Designed for forklift loading of Euro-pallets (stabilizes the bike and lifts tires slightly).
    - Developed three alternative Bill of Materials (BOM) files: Budget Salvage, Industrial Standa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
2026-04-06 Finalize industrial e-bakfiets design with screw-driven stabilizers and modular docs
    - Implemented a screw-driven stabilizer system using M16/M20 threaded rods and 19mm hex drive interfaces (wrench or cordless drill compatible).
    - Designed for safe forklift loading of heavy Euro-pallets by providing a stable, adjustable 4-point base.
    - Integrated MZ ETZ 150/251 moped steel rims for high-pressure and rugged builds.
    - Developed three alternative Bill of Materials (BOM) fi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
2026-04-06 Finalize industrial e-bakfiets design with full fastener and brake specs
    - Comprehensive fastener audit and specification (M14, M10, M8, M6, M5) with appropriate grades (8.8, 10.9, 12.9).
    - Detailed Brake System redesign: 203mm front rotors with 4-piston hydraulic calipers and 180mm rear rotors with parking lock.
    - Implemented a screw-driven stabilizer system with M16/M20 threaded rods and 19mm hex drive for drill operation.
    - Integrated a 16-inch rear wheel (MZ ETZ moped rims) for maximized torque and low center of gravity.
    - Redesigned the steering head using 7202 angular contact bearings and 1-1/4" Sch 40 pipe for a no-machining assembly.
    - Refactored project into five technical modules: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
2026-04-06 Finalize industrial e-bakfiets design with full cable layout and modular docs
    - Optimized cable and Bowden cable routing for shortest possible paths while avoiding mechanical interference.
    - Implemented a comprehensive cable protection system using UV-resistant PA6 corrugated tubing, spiral wraps, and welded 'Cable Bridges'.
    - Defined minimum bend radii (10x cable diameter) and specific routing instructions for steering head junctions.
    - Verified mechanical integrity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
2026-04-07 Finalize industrial e-bakfiets complete engineering design documentation
    - Refactored project into a modular documentation system with five technical modules.
    - Developed three alternative Bill of Materials (BOM) configurations: Budget Salvage (~$625), Industrial Standard (~$1,940), and Heavy Duty (~$3,810).
    - Redesigned Steering System: Replaced EC34 headset with 7202 angular contact bearings and a 1-1/4" Sch 40 pipe 'no-machining' assembly method.
    - Implemented Decentralized Electrical System: Dual localized battery/controller units linked by a thick 8AWG equalizer wire for load balancing and redundancy.
    - Redesigned Rear Wheel: Adopted 16-inch diameter (MZ ETZ moped steel rims) for maximi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
2026-04-07 Finalize complete mechanical design for industrial e-bakfiets
    - Refactored project into a 12-module documentation system with three alternative BOMs.
    - Detailed Mechanical Geometry: 68° head angle, 35mm rake, and ~73mm trail optimized for cargo.
    - Custom Front Fork Design: 200mm crown inner width for 155mm car tire and reinforced dropouts.
    - Technical Subassemblies: Specified dimensions for 7202 bearing stopping elements, 5mm motor flange plates, and 6mm torque arms.
    - Decentralized Electrical System: Dual power units linked by 8AWG equalizer wire and oversized ESC housings.
    - Screw-Driven Stabilizers: Four M16/M20 telescopic legs for forklift-safe loading.
    - Optimized Drivetrain: 16-inch r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
2026-04-07 Finalize professional mechanical design for industrial e-bakfiets
    - Detailed Mechanical Geometry: 68° head angle, 35mm rake, and ~73mm trail.
    - Custom Front Fork Design: 200mm crown inner width for 155mm car tire.
    - Steering Upgrades: Integrated physical stops (+/- 45°), 15mm reinforced linkage rods, and 7202 angular contact bearings.
    - Industrial Protection: 170mm wide steel mudguards with rolled safety edges.
    - Stability: Heavy-duty central bipod kickstand (350mm base) + screw-driven stabilizers.
    - Rear Wheel Lacing: Detailed 10G spoke spec and 2-cross pattern for ETZ moped rims.
    - Decentralized Elect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
2026-04-07 Finalize professional mechanical design for industrial e-bakfiets
    - Detailed BSA 68mm Bottom Bracket shell integration and custom 8mm derailleur hanger design.
    - Implemented Battery Retention System: Rubber-lined stainless steel straps and EVA foam padding.
    - Detailed Bipod Kickstand: 350mm base, 10mm pivot with grease port, and dual-spring return.
    - Redesigned Steering: 7202 angular contact bearings in 1-1/4\" Sch 40 pipe with physical stops (+/- 45°).
    - Optimized Rear Wheel: 16-inch moped rim with 10G spoke spec and 2-cross pattern.
    - Cargo Box: 12mm Marine Plywood with steel angle reinforcement and D-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
2026-04-07 Finalize professional mechanical design for industrial e-bakfiets
    - Refined Frame Geometry: 285mm BB height for 115mm pedal clearance and tapered rear transition for 16\" wheel.
    - Detailed Steering Linkage: 100mm steering arms for 1:1 ratio and +/- 45° stops.
    - Integrated BSA 68mm Bottom Bracket shell and custom 8mm derailleur hanger.
    - Redesigned Steering: 7202 angular contact bearings in 1-1/4\" Sch 40 pipe.
    - Opti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
2026-04-07 Finalize professional mechanical design for industrial e-bakfiets
    - Refactored project into a 13-module documentation system with three alternative BOMs.
    - Designed Weather Protection: Modular 15mm steel frame canopy with polycarbonate windshield and PVC curtains.
    - Implemented Chain Management: Full-length HDPE chain tubes with integrated frame mounting.
    - Designed Modular Cargo Dividers: 50mm E-track rails and adjustable plywood partition panels.
    - Refined Frame Geometry: 285mm BB height for pedal clearance and tapered transition for 16\" rear wheel.
    - Detailed Steering System: 7202 bearings, no-machining assembly, and integrated physical stops (+/- 45°).
    - Optimized Rear Wheel: 16-inch m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
2026-04-07 Finalize complete professional design for industrial e-bakfiets with 13 verified SVGs
    - Created a complete suite of 13 technical SVG drawings (1px = 1mm scale) including Full Assembly, Frame Top/Side views, Electrical Wiring, and Part-specific details.
    - Part Detail SVGs: Motor Flange Plates, Torque Arms, Steering Stopping Elements, and Rear Dropouts with integrated hangers.
    - Developed `svg_design_auditor.py` and `geometry_verify.py` to programmatically verify dimensional consistency and stability.
    - Innovative Steering: 7202 bearings in 1-1/4\" Sch 40 pipe with a no-machining radial-locking assembly and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
2026-04-08 Finalize professional 3D mechanical design for industrial e-bakfiets
    - Developed technically perfect 3D models in OpenSCAD (docs/models/) for all major systems.
    - parts.scad: Foundation library with parameterized industrial primitives (tubes, pipes, bearings).
    - full_assembly.scad: Programmatic 3D integration of frame, fork, steering, wheels, and electronics.
    - Fixed modeling hallucinations: Corrected 13\" car tire extrusion and decentralized ESC box placements.
    - Verified PNG Renders: Generated 20 non-zero byte PNGs (Front, Side, Top, Perspective) for all modules.
    - Innovative Steering: 7202 bearings in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
    [frame.scad, front_fork.scad, front_wheel_assy.scad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]
2026-04-08 Finalize professional 3D mechanical design for industrial e-bakfiets
    - Rewrote and aligned all OpenSCAD models (docs/models/) on a standard X=Forward, Y=Right, Z=Up coordinate system.
    - Corrected modeling hallucinations: Redesigned the 13\" car tire using `rotate_extrude` and fixed spatial mating of the fork and steerer.
    - Integrated Master Assembly: Composed frame, steering, fork, and wheels into a consistent 3D model.
    - Developed `openscad_validator.py` to ensure geometric integrity (non-null STL compilation) of all models.
    - Enhanced `openscad_renderer.py` using `xvfb-run -a` to generate 20 verified hi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
    [frame.scad, front_fork.scad, front_wheel_assy.scad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]
2026-04-08 Finalize complete professional engineering design for industrial e-bakfiets
    - Refactored project into 13-module documentation system with three alternative BOMs.
    - Centralized all dimensions in `master_dims.scad` for 100% geometric consistency.
    - Developed technically perfect 3D models in OpenSCAD with correct mating and alignment.
    - Integrated high-fidelity visual renders (24 PNGs) covering orthographic and perspective views.
    - Innovative Steering: 7202 bearings in 1-1/4\" Sch 40 pipe with radial locking and +/- 45° stops.
    - Decentralized Electrical: Dual localized units and 8AWG equalizer wire for high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
    [frame.scad, front_fork.scad, full_assembly.scad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]
2026-04-08 Complete Industrial E-Bakfiets engineering design and documentation package.
    - 13 detailed technical modules (Frame, Steering, Electrical, etc.)
    - 3 alternative Bill of Materials (Budget, Standard, Heavy Duty)
    - Parametric 3D OpenSCAD models with master dimensions
    - 18 SVG technical drawings with First Angle Orthographic projections
    - Verified mechanical fits and clearances via custom audit tools
    - High-resolution renders for visual verification
    [frame.scad, front_fork.scad, full_assembly.scad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]
2026-04-08 Implement Integrated Surface-to-Surface engineering design for Industrial E-Bakfiets.
    - Redesigned 3D OpenSCAD assembly using 'Surface-to-Surface' mating logic rooted at the front automotive tire center.
    - Updated 13 technical modules with detailed descriptions of elements and decentralized architecture.
    - Created 3 alternative BOM files (Budget, Standard, Heavy Duty).
    - Revised 18 SVG technical drawings to reflect the integrated design and 1950mm wheelbase.
    - Verified mechanical integrity and clearances via custom audit tools.
    - Generated high-resolution renders for final design inspection.
    - Preserved original README for historical reference.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
    [frame.scad, front_fork.scad, front_wheel_assy.scad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]
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2026-04-09 feat: finalize engineering design package for industrial e-bakfiets v8
    - Refined OpenSCAD models with industrial gussets, cable guides, and assembly patterns.
    - Synchronized all 18 SVG technical drawings with the v8 design improvements.
    - Updated documentation modules to include detailed reinforcement and sourcing data.
    - Standardized 3D model code with parametric color variables and resolution controls.
    - Verified design stability with extreme parametric stress tests and clash audits.
    - Generated final, polished high-fidelity renders for all modules.
    [frame.scad, front_fork.scad, parts.scad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]
2026-04-10 feat: finalize industrial e-bakfiets engineering design v9
    This submission completes the engineering design and documentation for the industrial cargo e-bike.
    Key Enhancements:
    - Re-engineered v9 Front Wheel: Industrial 13-inch split rim with 270mm PCD M8 bolt pattern and 16mm flange sandwich.
    - High-Fidelity Hub Motor: M14 axle with 10mm torque-retention flats and perimeter-bolted side covers.
    - Reinforced Front Fork: Vertical dropout slots with 10.2mm clearance, torque arm mount, and crown gussets.
    - Documentation Suite: 15 technical modules and 3 alternative BOMs (Budget, Standard, Heavy Duty).
    - Parametric Models: Centralized 'master_dims.scad' and nested serial transformation chain in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
    [frame.scad, front_fork.scad, parts.scad]
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2026-04-12 Finalize Industrial E-Bakfiets design v22.
    - Resolved assembly duplication by removing top-level module calls in sub-components.
    - Corrected steering linkage kinematics using exact point-to-point vector mapping in Root coordinates.
    - Updated all renders to reflect version 22 of the assembly.
    - Maintained 100% numerical synchronization between documentation and 3D model.
    - Preserved original README as README_ORIGINAL.md.
    [frame.scad, front_fork.scad, front_wheel_assy.scad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]
2026-04-12 Complete Industrial E-Bakfiets design development (v26)
    - Finalized parametric OpenSCAD assembly with corrected rear geometry and kinematics.
    - Implemented 15 detailed documentation modules and 3 alternative BOMs.
    - Refined industrial details (cooling fins, hollow axle, steering clearance).
    - Relocated electronics for optimized center of gravity.
    - Generated high-resolution renders for all major views.
    [frame.scad, full_assembly.scad, master_dims.scad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]
2026-04-12 Release Industrial E-Bakfiets design v27 with 15 documentation modules and 3 BOM tiers.
    - Finalized parametric OpenSCAD assembly with corrected rear axle geometry (-50mm dropout offset).
    - Implemented 15 technical documentation modules covering all mechanical and electrical systems.
    - Created 3 alternative BOM files (Budget Salvage, Industrial Standard, Heavy Duty).
    - Relocated electronics to protected under-bed housing.
    - Generated high-resolution orthographic and perspective renders.
    - Preserved original project documentation as README_ORIGINAL.md.
    - Verified dimensional consistency and mechanical integrity.
    [frame.scad, front_fork.scad, front_wheel_assy.scad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]
2026-04-13 Release Industrial E-Bakfiets design v27 with 15 documentation modules and 3 BOM tiers.
    - Finalized parametric OpenSCAD assembly with corrected rear axle geometry.
    - Implemented 15 technical documentation modules with detailed descriptions of all elements.
    - Created 3 alternative BOM files (Budget, Industrial, Heavy Duty).
    - Synchronized all documentation dimensions with the 3D model (v27).
    - Optimized drivetrain and steering linkage parameters for industrial use.
    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
    [master_dims.scad]
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2026-04-14 Finalize high-fidelity Industrial E-Bakfiets design (v27)
    - Completed 15 technical documentation modules with orthographic details.
    - Refined high-fidelity OpenSCAD model with corrected tire/rim interfaces and frame geometry.
    - Synchronized dimensional parameters across master_dims.scad and markdown docs.
    - Updated full render suite in docs/renders/ including orthographic and perspective views.
    - Standardized frame spars to 40x40mm for heavy-duty industrial compliance.
    - Included automated audit and rendering toolset in docs/models/.
    [diag_fork.scad, diag_frame.scad, diag_tire.scad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]
2026-04-14 finalize industrial e-bakfiets design package v27
    - Refined OpenSCAD models for front wheel, fork, and mudguard assembly.
    - Implemented a robust 3-point mudguard anchoring system (crown bracket + stays).
    - Synchronized all documentation (15 modules) and BOMs (3 tiers) with the 40x40mm spar standard.
    - Updated technical drawings (SVG) for dimensional consistency.
    - Generated high-resolution renders for all sub-assemblies.
    - Ensured zero mechanical interference and correct parentage in the master assembly.
    [diag_front_end.scad, diag_front_wheel.scad, front_fork.scad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]
2026-04-14 integrate stock hub motor and reinforce rim-motor interface
    - Standardized the front drive on the Golden Motor Magic Pie 5 (Fatbike version) with 190mm axle.
    - Redesigned the rim-motor interface with 12mm adapter plates to bridge spoke flanges to car rim.
    - Reduced rim bolt PCD to 260mm and increased adapter OD to 330mm to ensure full structural support for fasteners.
    - Reinforced the 'car_rim_half' flange and transition web in the OpenSCAD model.
    - Updated 'front_wheel.md' and BOMs with specific vendor models (Golden Motor, QS Motor) and pricing.
    - Synchronized all technical renders to reflect the updated structural geometry.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
    [master_dims.scad, parts.scad]
2026-04-15 Finalize Industrial E-Bakfiets design package (v28)
    - Standardized front wheel assembly with Golden Motor Magic Pie 5 (190mm axle) and 260mm PCD automotive rim interface.
    - Synchronized all 15 technical documentation modules and 3 BOM tiers (Budget, Industrial, Heavy Duty) with master dimensions.
    - Verified zero mechanical interference in the OpenSCAD parametric model.
    - Refreshed high-resolution visual assets (Orthographic, Exploded, X-Ray) in `docs/renders/`.
    - Preserved original project description as README_ORIGINAL.md.
    [front_wheel_exploded.scad, front_wheel_xray.scad, parts.scad]
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2026-05-05 docs: re-generate all core renders after parts.scad improvements
    Re-ran all project renders using render_manager.py after verifying
    the improved geometry in parts.scad. Changes include:
    - Corrected tire bead and tread block orientations.
    - Parametric disc rotor positioning.
    - Corrected axial offsets for crank arms.
    - Fixed rod end flattening logic.
    - Improved mudguard structural thickness.
    Verified all models via static analysis and a custom technical audit
    script before regeneration.
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2026-10-14 Audit and fix OpenSCAD models starting from front wheel
    - Centralized rim_clamp_pcd=290 in master_dims.scad so outer split rim fasteners sit inside the 330mm rim bead.
    - Fixed hub_motor_dd housing geometry in parts.scad to prevent collision with adapter plates.
    - Corrected disc_caliper mounting hole axis and 51mm ISO spacing to align with fork ISO tabs.
    - Fixed mudguard_crown_bracket offset vector and stay orientation in parts.scad and full_assembly.scad.
    - Aligned front fork dropouts to front_hub_dropout/2=95mm inner face and matched torque arm length/rotation.
    - Added steering mast tube in frame.scad and mated handlebars and upper bell crank cleanly to the frame.
    - Aligned steering linkage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
2026-10-14 Comprehensive audit and fix of OpenSCAD drawings and subassemblies
    - Fixed car_rim_half bead seat orientation so split rim halves mate face-to-face at Y=0 with bead seats extending from Y=10mm to Y=50mm.
    - Aligned car_tire_13in tire beads at Y=±50mm to match rim bead seat flanges.
    - Fixed hub_motor_dd housing geometry (210mm diameter, 76mm width) to clear adapter plate inner bore.
    - Fixed front_wheel_exploded.scad to avoid duplicate adapter plates.
    - Commented out top-level ghost call in docs/models/front_wheel/wheel_155_75_r13.scad.
    - Aligned front_fork dropouts to ±95mm (front_hub_dropout/2) and matched torque arm anchor hole.
    - Corrected disc_caliper hole axes along X with 51mm ISO spac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
2026-10-14 Audit and fix OpenSCAD drawing files and assembly geometry
    Corrected front wheel, fork, frame, and full assembly SCAD models:
    - Updated car_rim_half bead flange dimensions to prevent tire sidewall penetration.
    - Fixed dropout_z_offset in master_dims.scad to level front and rear wheels on Z=0.
    - Corrected torque arm, brake caliper, and mudguard crown bracket geometry and offsets.
    - Removed top-level module invocations in includes to eliminate ghost geometry.
    - Regenerated all assembly documentation renders.
2026-10-15 Fix OpenSCAD models: box overlap, front wheel assembly, steering linkage, and renders
    - Moved driver steering mast tube, bottom bracket, pedals, seat post, and saddle behind the cargo box in frame.scad and full_assembly.scad to eliminate component overlap.
    - Updated front wheel split rim half dimensions, tire bead interfaces, adapter flange offsets, and fastener patterns in parts.scad and front_wheel_exploded.scad.
    - Re-aligned pushrod linkages between front fork bell crank and rear driver steering column bell crank in full_assembly.scad.
    - Updated render_manager.py camera viewports to capture the entire bicycle without clipping and added a rear-quarter perspective render.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
